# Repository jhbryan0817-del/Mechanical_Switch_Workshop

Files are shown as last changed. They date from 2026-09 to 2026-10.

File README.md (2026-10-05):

# Mechanical Switch

A compact, servo-driven mechanical switch enclosure with a Waveshare ESP32 servo driver and internal battery. The current design has a flat servo floor, lowered servo restraints, reinforced PCB support, a smaller rounded cable pocket, and a centred actuator window.

Updated **5 October 2026**. [Fusion and STEP files](3d/) · [Printable STLs](3d/stl/) · [Bill of materials](bom/BOM.md). Print one of each STL at 100% scale (millimetres). Prototype: physical fit and actuator completion remain to be verified.

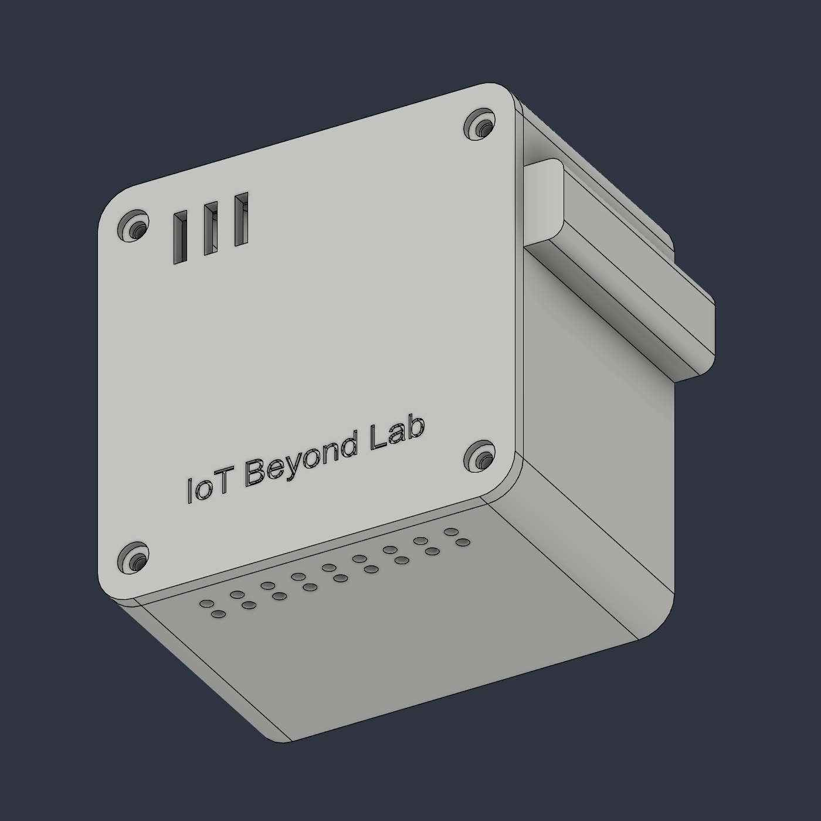
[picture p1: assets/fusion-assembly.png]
Closed enclosure

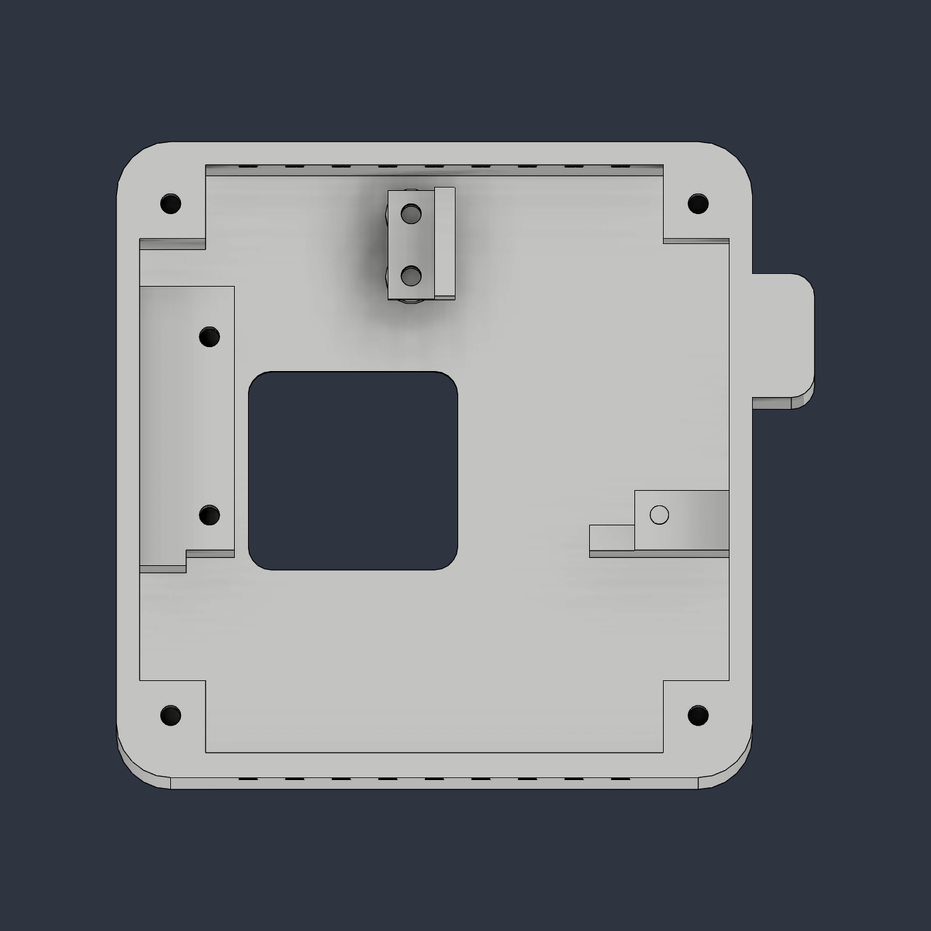
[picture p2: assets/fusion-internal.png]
Internal chassis

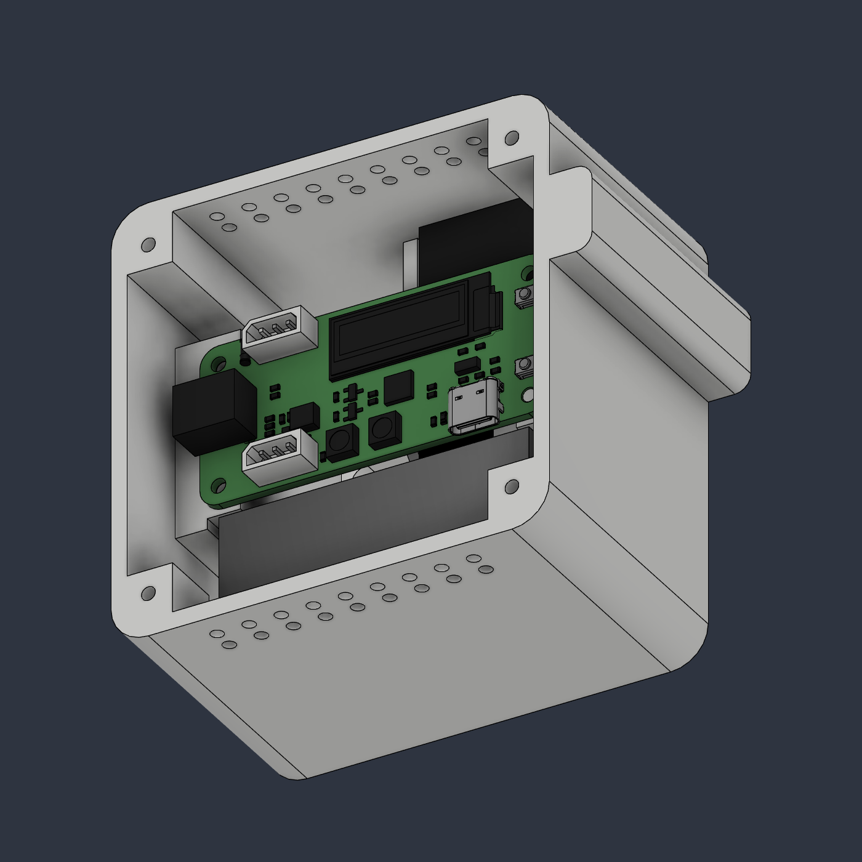
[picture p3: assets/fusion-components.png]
Servo, driver and battery layout


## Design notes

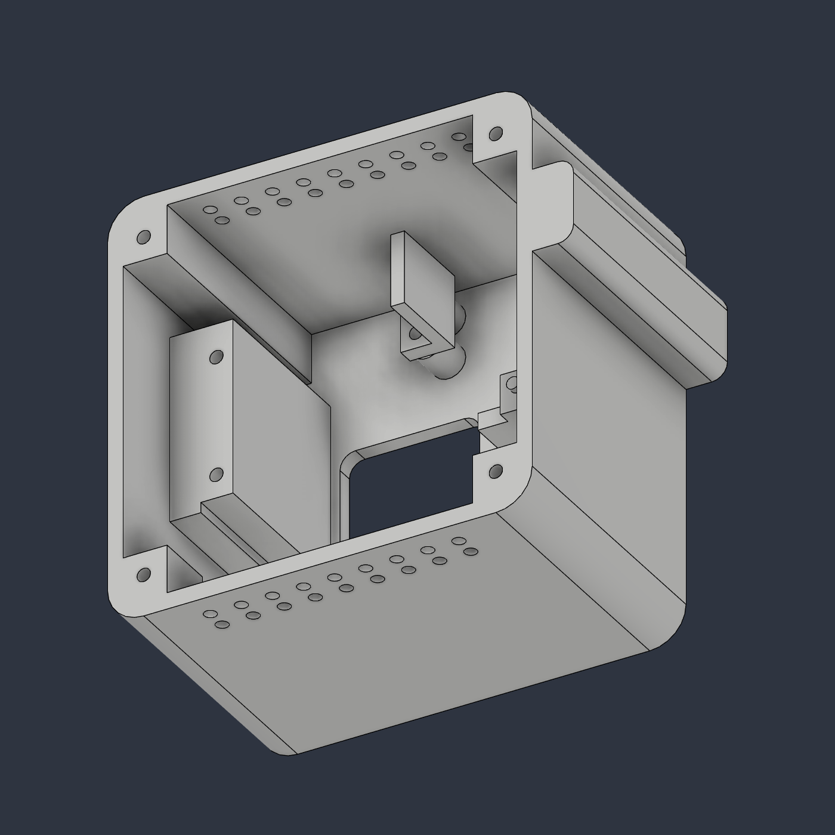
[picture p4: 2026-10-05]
assets/fusion-chassis-iso.png

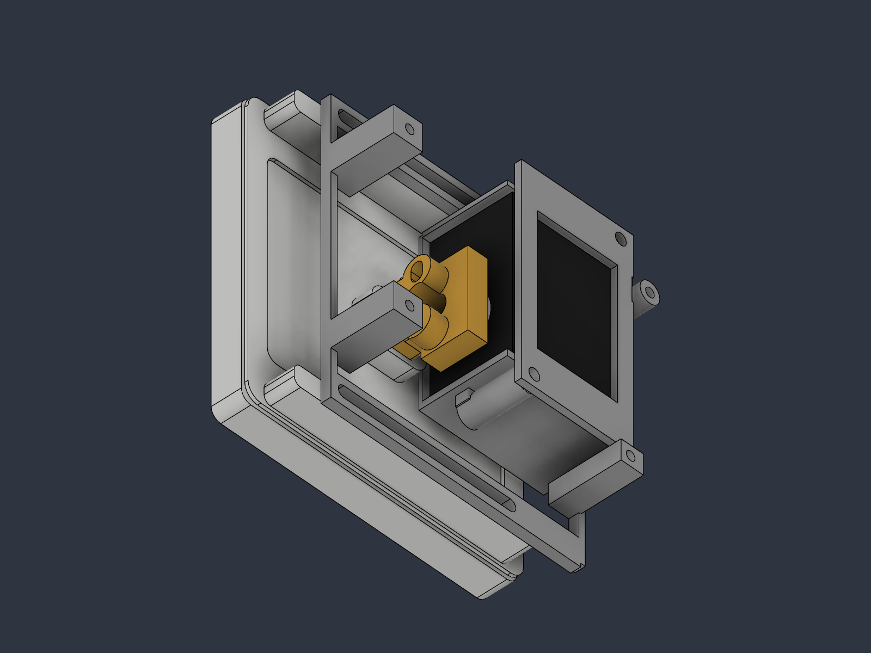
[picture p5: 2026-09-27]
assets/fusion-mechanism.png

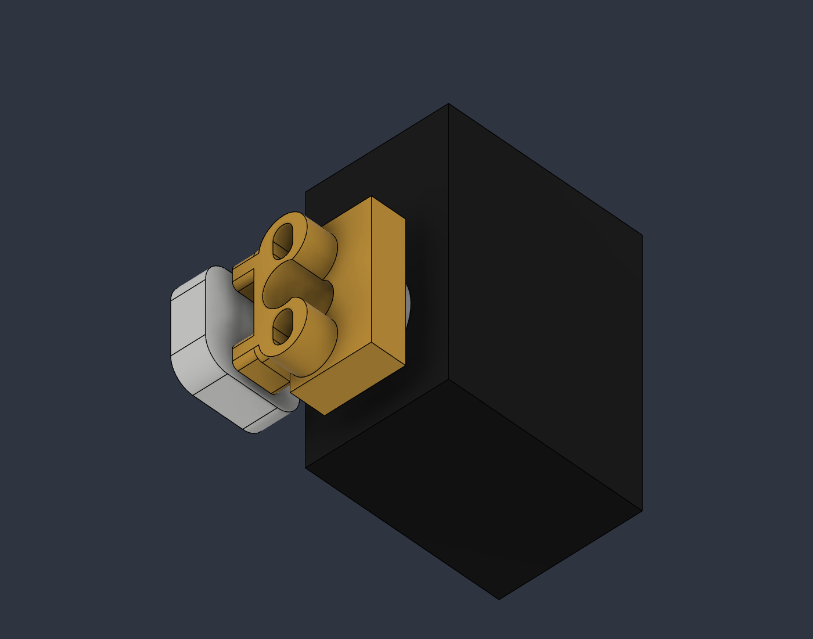
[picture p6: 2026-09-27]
assets/fusion-direct-drive.png

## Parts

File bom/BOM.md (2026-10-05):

# Bill of materials

| Qty | Item | Notes |
|---:|---|---|
| 1 each | Chassis, servo stop, cover | Current [STLs](../3d/stl/); millimetres, 100% scale |
| 1 | STS3215/ST3215 servo and stock horn | Confirm actual voltage variant and case/lead dimensions |
| 1 | Waveshare Servo Driver with ESP32 | Manufacturer PCB model included in the CAD assembly |
| 1 | Gens ace GEA8502S60E2 850 mAh 2S 7.4 V battery, EC2 | Nominal 58 × 32 × 20 mm reference envelope |
| 1 | Mating EC2 internal harness | Match polarity, insulation and load rating |
| 1 each | Inline fuse/holder and suitable 2S low-voltage protection | Select for measured load; hardware fit is not yet modelled |
| 1 | Compact DC power pigtail | Board input: 5.5 × 2.1 mm; check connector fit |
| 1 | External 2S LiPo balance charger | Compatible discharge and balance connectors |
| 1 set | Insulating pad and removable battery retention | Flat battery floor; retention method remains to be chosen |
| 4 | M3 cover screws | Approximately 12 mm starting length; verify engagement |
| 2 | M3 servo-stop screws | Approximately 8 mm starting length; 3.2 mm flange and Ø2.6 mm pilots; verify bottoming |
| 2 | Left PCB screws | Verify actual Ø2.75 mm board-hole clearance before using M3 |
| As needed | Servo leads, adhesive, actuator and actuator hardware | Actuator remains to be designed |

The servo reference is lowered 5.15 mm. The floor-to-case gap is 0.30 mm, both hold-down surfaces have 0.25 mm clearance above the case, and the horizontal stop has 0.35 mm side clearance. The stop's screw base and chassis pilots retain their original positions. These are CAD clearances; confirm them on printed parts.

The actuator and real switch interface remain unfinished. The existing tilted-rocker reference overlap with the chassis is not resolved by this revision. The battery model represents its nominal envelope; connector, protection hardware and cable routing require physical fit checks.

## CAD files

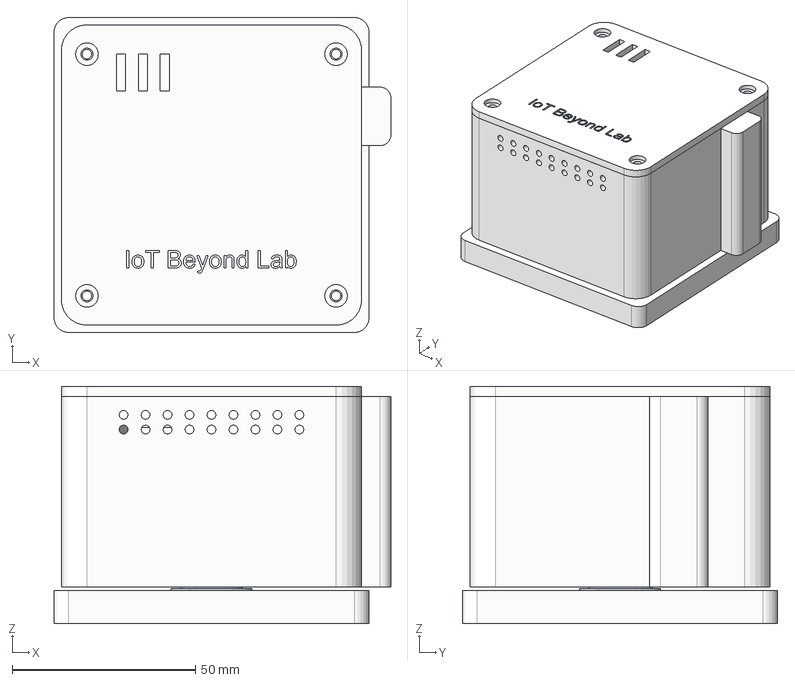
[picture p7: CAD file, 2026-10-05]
3d/Mechanical_Switch.step
92.0 x 86.0 x 64.8 mm

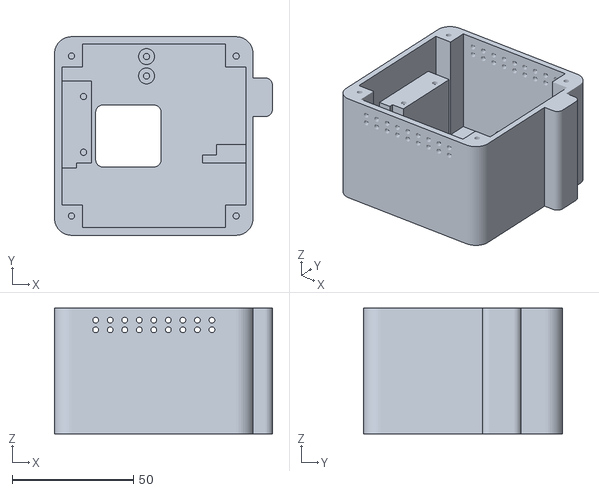
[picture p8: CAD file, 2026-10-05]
3d/stl/01_integrated_chassis.stl
90.0 x 82.0 x 52.0

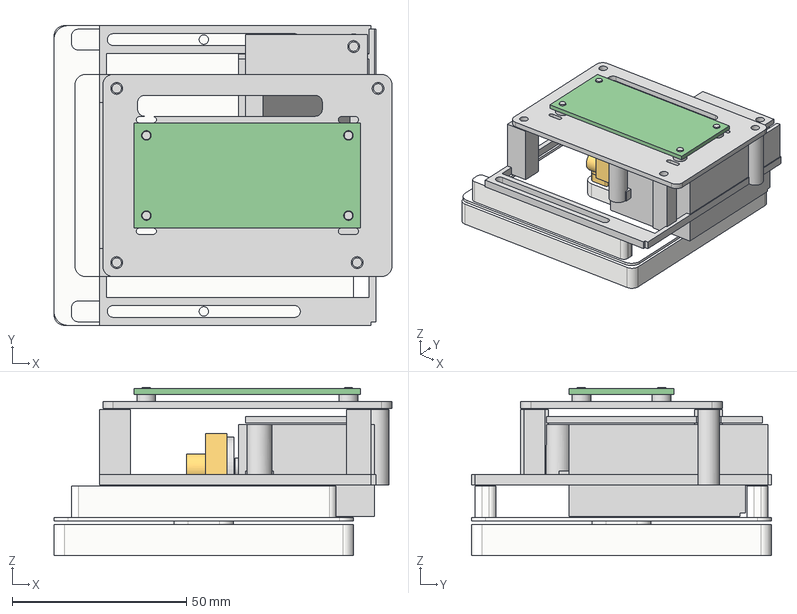
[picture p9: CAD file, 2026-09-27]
cad/Mechanical_Switch_v03.step
97.0 x 86.0 x 48.3 mm

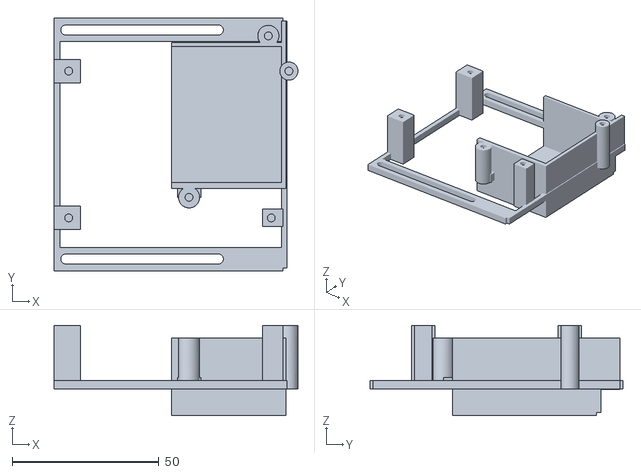
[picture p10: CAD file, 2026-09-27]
stl/02_sliding_servo_chassis.stl
83.1 x 86.0 x 30.7

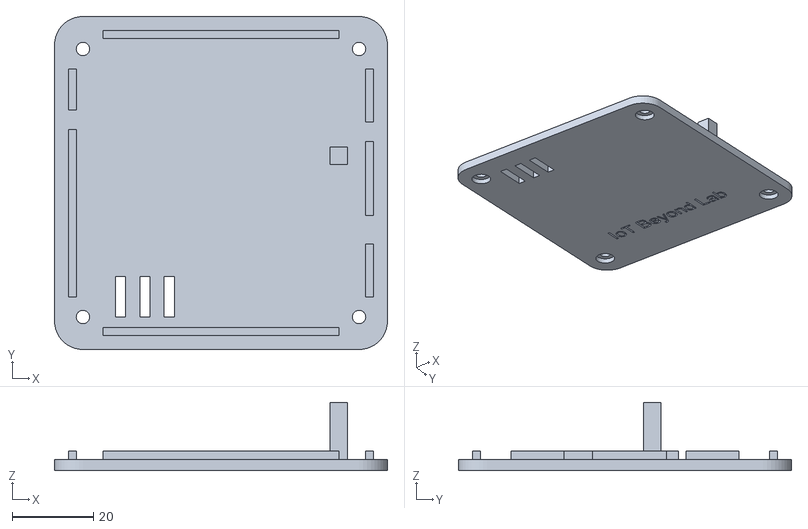
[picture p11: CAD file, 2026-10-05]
3d/stl/03_cover_and_pcb_capture.stl
82.0 x 82.0 x 16.9

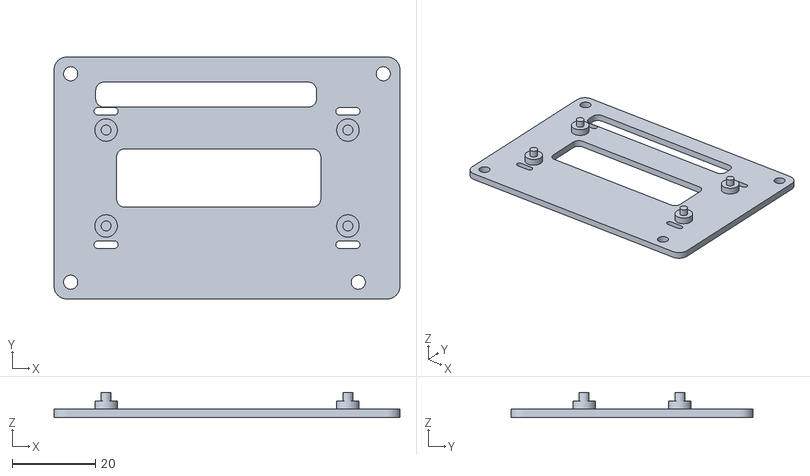
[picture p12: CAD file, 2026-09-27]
stl/05_controller_shelf.stl
83.0 x 58.0 x 6.00

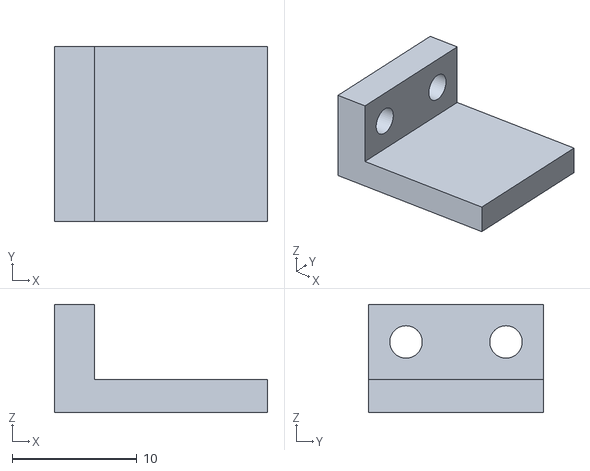
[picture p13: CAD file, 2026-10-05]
3d/stl/02_horizontal_servo_stop.stl
17.0 x 14.0 x 8.65

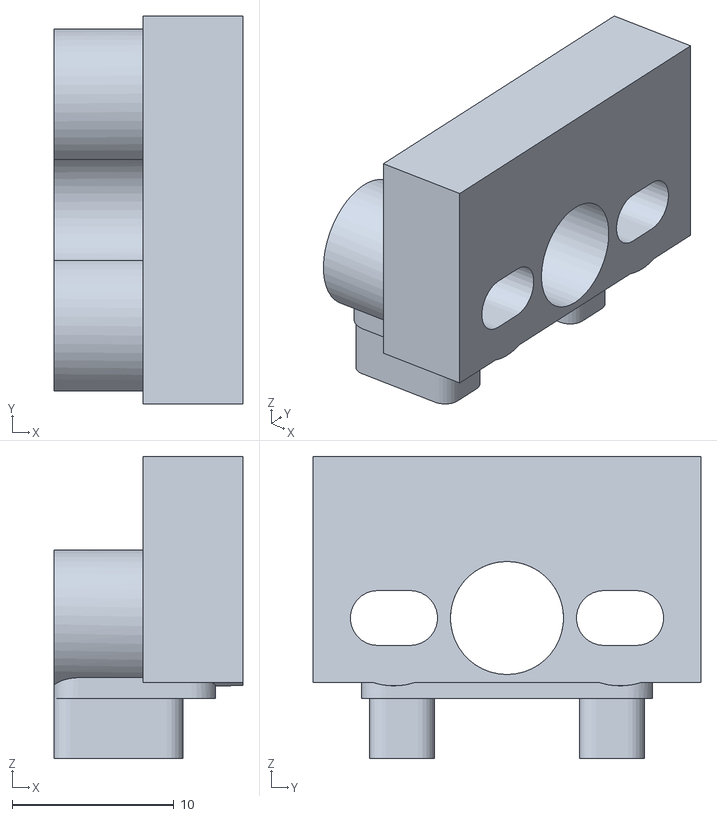
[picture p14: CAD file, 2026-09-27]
stl/04_integral_rocking_shoe.stl
11.7 x 24.0 x 18.7

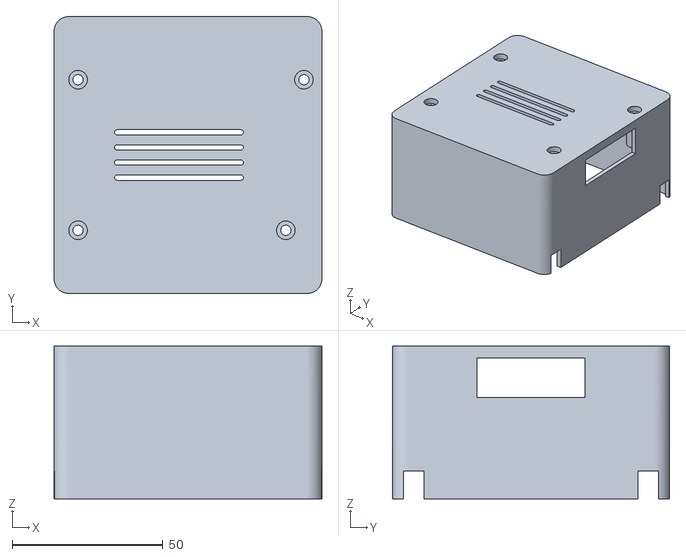
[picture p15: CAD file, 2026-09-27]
stl/06_rounded_enclosure.stl
89.0 x 92.0 x 50.7

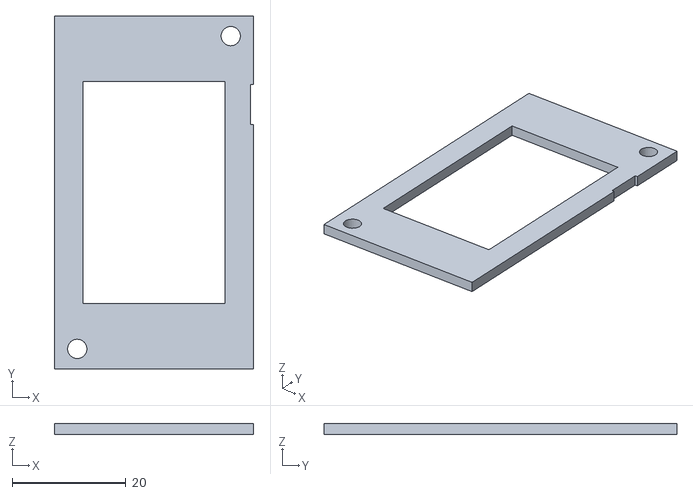
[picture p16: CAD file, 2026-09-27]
stl/03_servo_clamp.stl
35.0 x 62.0 x 2.00

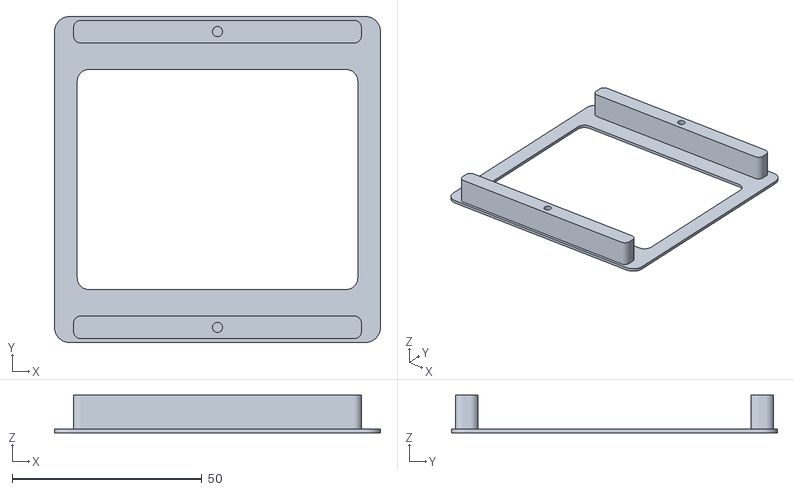
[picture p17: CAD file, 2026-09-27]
stl/01_mounting_frame.stl
86.0 x 86.0 x 10.00

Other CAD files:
3d/Mechanical_Switch.f3d
cad/Mechanical_Switch_v03.f3d

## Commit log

2026-09-27 Add v0.1 Fusion switch actuator and workshop build guide
    [01_faceplate_tape_frame.stl, 02_xy_bridge.stl, 03_lower_guide_and_pillars.stl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]
2026-09-27 Redesign actuator with direct compliant paddle and compact enclosure
    [01_adhesive_base.stl, 01_faceplate_tape_frame.stl, 02_sliding_servo_chassis.stl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]
2026-09-27 Frame the full enclosed assembly in saved Fusion previews
    [Mechanical_Switch_v02.f3d]
2026-09-27 Simplify Fusion assembly and reinforce direct rocking shoe
    [01_adhesive_base.stl, 01_mounting_frame.stl, 02_sliding_servo_chassis.stl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]
2026-09-28 Update to compact branded Fusion design with closed cover and print-ready exports
    [01_integrated_chassis.stl, 01_mounting_frame.stl, 02_servo_clamp.stl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]
2026-09-30 Document Fusion-only v0.5 battery enclosure revision
2026-09-30 Document Fusion-only v0.6 forward layout and cable groove
2026-09-30 Document Fusion-only v0.7 enclosure cleanup
2026-10-02 Export current Mechanical Switch print parts and update documentation
    [01_integrated_chassis.stl, 02_horizontal_servo_stop.stl, 02_servo_clamp.stl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]
2026-10-05 Lower servo mounting, refine chassis, and simplify project files
    [01_integrated_chassis.stl, 02_horizontal_servo_stop.stl, 02_servo_clamp.stl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]
